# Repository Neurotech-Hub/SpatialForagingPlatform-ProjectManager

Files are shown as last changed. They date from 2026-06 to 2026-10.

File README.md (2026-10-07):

# Spatial Foraging Platform

A modular home-cage platform that converts the cage floor into a programmable
foraging environment for freely moving rodents. Distributed reward delivery and
spatial cueing within a scalable, synchronized architecture enable continuous,
ethologically grounded behavior compatible with chronic neural recordings.

**[View design (Fusion 360)](https://a360.co/4dwOh8e)** — 3D model and mounting
outline. Mounting DXF and fastener notes live in [`hardware/`](hardware/).

This repository is the **planning, documentation, and manuscript hub** for the
project. Firmware, base-station GUI, and analysis code live in
[Neurotech-Hub/SFM](https://github.com/Neurotech-Hub/SFM) and are linked from
the [Related repositories](#related-repositories) table below.

Funded by the McDonnell Center NRP (PI: Gaidica). Total budget: $40,000 over 12
months. See [`references/McDonnell-NRP_GAIDICA.pdf`](references/McDonnell-NRP_GAIDICA.pdf)
for the funded proposal.

## Current status

| Field | Value |
| --- | --- |
| Phase | Phase 3A — first ABC startup; HLAB bandit learning confirmed |
| Hardware status | Alpha (ABC 2-node in first runs; one HLAB node does not fully raise) |
| Software status | Alpha (open: GUI pellet count; dome-open raise safeguard) |
| Week | Week 17 (as of 2026-10-07; see [`PROJECT.md`](PROJECT.md)) |

## Quick links

- [`PROJECT.md`](PROJECT.md) — master roadmap: phases, milestones, exit criteria, checkbox tasks
- [Operations](#operations) — flash firmware, bring up the Pi, run a session, generate reports
- [`docs/`](docs/) — design + requirements documents (architecture, dispense cycle, sync, UI/UX, calibration, etc.)
- [`docs/dispense-cycle.md`](docs/dispense-cycle.md) — dispense cycle flowchart, sensor pinouts, CAN events, and heartbeat snapshot
- [`docs/user-api.md`](docs/user-api.md) — experiment API, session CSV schema, and behavior reports
- [`docs/function-checks.md`](docs/function-checks.md) — pre-session bring-up checklist
- [`hardware/`](hardware/) — hardware design artifacts (e.g. 3D / DXF)
- [`meetings/`](meetings/) — cross-lab meeting notes
- [`pulse/`](pulse/) — weekly progress (shipped / in progress / blocked)
- [`bom/`](bom/) — budget tracking against the $40k grant
- [`references/`](references/) — grant proposal and source planning documents
- [`manuscript/`](manuscript/) — manuscript drafting (Phase 8+)
- [`CONTRIBUTING.md`](CONTRIBUTING.md) — how to contribute

## Collaborators

| Lab | Role | Lead | GitHub |
| --- | --- | --- | --- |
| Neurotech Hub (NTH) | Engineering lead — electronics, firmware, host UI, fabrication, integration, dissemination | Matt Gaidica, PhD | TBD |
| Animal Behavior Core (ABC) | UI/UX feedback, common task structures, behavioral benchmarking, animal metrics report | Susan Maloney, PhD | TBD |
| Hengen Lab (HLAB) | Custom experiment authoring, in vivo electrophysiology validation, recording sync | Keith Hengen, PhD | TBD |

## Related repositories

The repositories below hold the actual artifacts produced by this project. This
planning repo links to them; it does not contain their source.

Firmware, GUI, and analysis all live in **[Neurotech-Hub/SFM](https://github.com/Neurotech-Hub/SFM)**
(formerly VFM).

| Domain | Repository | Owner | Status |
| --- | --- | --- | --- |
| Mechanical / CAD | TBD | NTH | TBD |
| Electronics / PCB | TBD | NTH | TBD |
| Module firmware | [SFM `firmware/`](https://github.com/Neurotech-Hub/SFM/tree/main/firmware) | NTH | Active — Arduino library `SFM` (ESP32-S3) |
| Base station / host UI  | [SFM `packages/dev_gui`](https://github.com/Neurotech-Hub/SFM/tree/main/packages/dev_gui) | NTH | Active — DearPyGui + CAN tooling |
| Experiment API | [experiment engine](https://github.com/Neurotech-Hub/SFM/tree/main/packages/dev_gui/base_station/experiment) | NTH / HLAB | Built-in templates; custom via copy-from |
| Analysis / reports | [sfm-analysis](https://github.com/Neurotech-Hub/SFM/tree/main/packages/sfm-analysis) ([PyPI](https://pypi.org/project/sfm-analysis/)) | NTH / ABC  | Active — `pip install sfm-analysis` |

When a CAD or PCB repo comes online, replace `TBD` with the URL and update the
status column.

## Operations

Operator path from a flashed node to a printable report. Long-form install and
troubleshooting live in SFM; this section is the hub.

```mermaid
flowchart LR
    flash[Flash SFM firmware]
    hat[Pi CAN HAT setup-can.sh]
    gui[python run.py]
    session[Start session in GUI]
    csv["~/sfm_logs session CSV"]
    report["sfm-report"]
    flash --> hat --> gui --> session --> csv --> report
```

All commands below assume a clone of [Neurotech-Hub/SFM](https://github.com/Neurotech-Hub/SFM).
CAN bitrate is **250 kbps**. Pre-session checks:
[`docs/function-checks.md`](docs/function-checks.md).

### Firmware

The Arduino library is `firmware/` (not the repo root). Copy or symlink it to
`Arduino/libraries/SFM`, or zip that folder and add it via *Sketch → Include
Library → Add .ZIP Library…*. Pin map:
[firmware/docs/WIRING.md](https://github.com/Neurotech-Hub/SFM/blob/main/firmware/docs/WIRING.md).
Dispense cycle:
[firmware/docs/DISPENSE_CYCLE.md](https://github.com/Neurotech-Hub/SFM/blob/main/firmware/docs/DISPENSE_CYCLE.md).

### One-time Raspberry Pi CAN HAT bring-up

Do this once per Pi before running against real hardware:

```bash
cd packages/dev_gui/deploy
sudo ./setup-can.sh            # reboots automatically if needed
sudo ./setup-can.sh --verify   # confirm can0 is healthy after reboot
```

Details: [deploy/README.md](https://github.com/Neurotech-Hub/SFM/blob/main/packages/dev_gui/deploy/README.md).
HAT pin-by-pin check (from `packages/dev_gui`): `python tests/test_hat.py`.

### Install and run the GUI

```bash
cd packages/dev_gui
pip install -r requirements.txt --break-system-packages
python run.py                  # real hardware on can0; logs default to ~/sfm_logs
```

Simulator (no hardware):

```bash
sudo modprobe vcan
sudo ip link add dev vcan0 type vcan
sudo ip link set up vcan0
# Terminal 1
python node_simulator.py --interface vcan0 --nodes 3
# Terminal 2
python run.py --interface vcan0 --nodes 3
```

GUI README: [packages/dev_gui/README.md](https://github.com/Neurotech-Hub/SFM/blob/main/packages/dev_gui/README.md).

### Run a session

In the GUI: pick a template, enter a session name, click Start. Session
activate broadcasts `SyncFlash` (every online node’s status LED solid ON for
500 ms) and fires a coincident BNC OUT pulse. Logs append to
`<log_dir>/<session_name>.csv` (default `~/sfm_logs`).

The base station stores MAC↔Node ID mappings in `~/.sfm/mac_id_registry.json`.
**Re-discover** in the GUI clears that file, broadcasts `ClearId` to node NVS,
and rediscovers from scratch.

### Behavior reports

Reports run on **any** workstation — Windows, macOS, or Linux. No Raspberry Pi
or hardware libraries. Install the SDK:

```bash
pip install sfm-analysis
```

```bash
sfm-report --demo --open                 # bundled demo; no rig or logs needed
sfm-report --list
sfm-report EXP-Test-02 --open
sfm-report "cohortA_*" --combine -o /tmp/cohortA.html
```

On the Pi, `python run_report.py` (from `packages/dev_gui`) is a thin wrapper
around the same CLI and uses the base station’s log-directory auto-detection
(external drive, else `~/sfm_logs`).

Canonical docs: [sfm-analysis README](https://github.com/Neurotech-Hub/SFM/blob/main/packages/sfm-analysis/README.md)
and [ANALYSIS_GUIDE.md](https://github.com/Neurotech-Hub/SFM/blob/main/packages/sfm-analysis/docs/ANALYSIS_GUIDE.md).
Experiment API and CSV schema: [`docs/user-api.md`](docs/user-api.md).

| Design | When it applies | Extra sections |
| --- | --- | --- |
| `default` | Any session (fallback) | Pellet accounting, latency, presence, funnel, faults |
| `free_feeding` | `free_feeding` template | Intake rate, reload delays |
| `fixed_and_random` | `fixed_and_random` template | Per-node role (off / fixed / random) |
| `probability_delivery` | `probability_delivery` template | Delivery-site distribution |
| `two_armed_bandit` | `two_armed_bandit` template | Choice, block/reversal curves, WSLS |

`--combine` builds a comparative report (cohort table, learning curve, quality
matrix). Time alignment: `relative` (default), `wall`, `trial`, or `event:<name>`.
JSON export is planned (`--json`); metrics are already computed separately from HTML.

## How to read this repo

If you are new here, read in this order:

1. This README — what we are building, where artifacts live, and how to operate.
2. [`PROJECT.md`](PROJECT.md) — current phase, what is in flight, what is next.
3. [`pulse/log.md`](pulse/log.md) — weekly shipped / in progress / blocked.
4. [`docs/architecture.md`](docs/architecture.md) — system architecture.
5. The relevant `docs/*.md` for your role (e.g. ABC: `ui-ux.md`, `maintenance.md`; HLAB: `user-api.md`, `sync-and-recording.md`).

## Abbreviations

Abbreviations used throughout this repository.

### Collaborators

| Abbreviation | Expansion |
| --- | --- |
| ABC | Animal Behavior Core |
| HLAB | Hengen Lab |
| NTH | Neurotech Hub |

### Project / process

| Abbreviation | Expansion |
| --- | --- |
| BOM | Bill of Materials |
| HW | Hardware (status field) |
| MVP | Minimum Viable Product |
| SFM | Spatial Foraging Module / [Neurotech-Hub/SFM](https://github.com/Neurotech-Hub/SFM) software repo |
| SW | Software (status field) |
| VFM | Former name of SFM (GitHub repo renamed 2026-08-27) |

### Hardware / electronics

| Abbreviation | Expansion |
| --- | --- |
| CAD | Computer-Aided Design |
| CAN | Controller Area Network (bus) |
| LED | Light-Emitting Diode |
| MCU | Microcontroller Unit |
| PCB | Printed Circuit Board |
| PCBA | Printed Circuit Board Assembly |
| TTL | Transistor-Transistor Logic (digital sync signal level) |

### Software / interfaces

| Abbreviation | Expansion |
| --- | --- |
| API | Application Programming Interface |
| CLI | Command-Line Interface |
| UI | User Interface |
| UX | User Experience |

### External references

| Abbreviation | Expansion |
| --- | --- |
| FED3 | Feeding Experimentation Device 3 (open-source rodent feeder, Kravitz lab) |

## License

Documentation, plans, and manuscript content in this repository are released
under [CC-BY-4.0](LICENSE). Code in linked sub-repositories carries its own
licensing.

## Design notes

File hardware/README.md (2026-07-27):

# Hardware

Design artifacts for the Spatial Foraging Module.

## 3D / mounting outline

| Item | Location |
| ---- | --- |
| Mounting outline (DXF) | [`3D/UserDXF.dxf`](3D/UserDXF.dxf) |
| View design (Fusion) | [a360.co/4dwOh8e](https://a360.co/4dwOh8e) |

The DXF is the outline required for mounting the Spatial Foraging Module.

- **Fasteners:** 4× M3 × 16 mm screws and 8× M3 nuts
- **Bedding height:** assumes ~10 mm

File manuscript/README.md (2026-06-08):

# Manuscript

This folder holds the methods/resource manuscript describing the Spatial
Foraging Platform: engineering, behavioral validation, electrophysiology /
sync validation, and analysis examples. Active drafting begins in
[Phase 8](../PROJECT.md#phase-8--manuscript-development).

## Source material

By the time Phase 8 starts, most of the manuscript content already exists
elsewhere in this repo:

- **Methods** — synthesized from [`../docs/`](../docs/) (architecture, sync, calibration, maintenance,
  user API).
- **Behavioral validation** — from the field test in Phase 5
  (see [`../docs/validation-plan.md`](../docs/validation-plan.md)).
- **Recording validation** — from HLAB's electrophysiology in Phases 3B and 5.
- **Resource statement** — from the [main README](../README.md) and the
  related-repository index.

## Planned contents (populated in Phase 8)

- `outline.md` — section assignments and target lengths.
- `figures/` — figure source files and exports.
- `sections/` — per-section drafts.
- `submission/` — final formatted manuscript and supplementary material.

## Publication route

To be selected at the start of Phase 8. Decision recorded as an ADR.

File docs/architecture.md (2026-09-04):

# Architecture

Captures the integrated system architecture for the platform.

## System overview

The Spatial Foraging Platform is a modular, network-connected behavioral apparatus
consisting of a Raspberry Pi 5 base station and up to N foraging modules (reference
deployment: 9 modules) connected over a CAN bus in a linear daisy-chain. Each
foraging module is an independent unit housing an ESP32S3, two stepper-motor pellet
dispensers, a sensor suite comprising a pellet presence sensor, home position sensor, and spring-loaded access port trigger, and status LEDs. The base
station orchestrates node discovery, session management, event logging, HTML
behavior reports from those logs, and synchronization with external recording
systems via BNC I/O. All modules are powered
from a single 12 V supply routed through the daisy-chain; the base station is powered
separately via USB-C.

```mermaid
flowchart LR
    subgraph bs [Base Station]
        RPi5[Raspberry Pi 5]
        CANHAT[CAN HAT]
        BNC_IN1[BNC In 1]
        BNC_IN2[BNC In 2]
        BNC_OUT[BNC Out]
        RPi5 --- CANHAT
    end

    subgraph pwr [12 V Power]
        PSU[8 A Supply]
    end

    PSU -->|12 V daisy-chain| M1
    PSU -->|12 V daisy-chain| M2
    PSU -->|12 V daisy-chain| MN

    CANHAT -->|CAN bus RJ45| M1

    subgraph M1 [Module 1]
        ESP1[ESP32S3 + CAN XCVR]
        TERM1[CAN termination OFF]
    end

    M1 -->|CAN bus RJ45| M2

    subgraph M2 [Module 2]
        ESP2[ESP32S3 + CAN XCVR]
        TERM2[CAN termination OFF]
    end

    M2 -->|CAN bus RJ45| MN

    subgraph MN ["Module N (last)"]
        ESPN[ESP32S3 + CAN XCVR]
        TERMN[CAN termination ON]
    end

    ExtSys[External System] -->|TTL/BNC| BNC_IN1
    ExtSys -->|TTL/BNC| BNC_IN2
    BNC_OUT -->|TTL/BNC| ExtSys
```

## Communication protocol

CAN bus was selected as the module network protocol for the following reasons:

- **Noise immunity** — differential signalling is robust over the cable lengths
typical in a home-cage arena.
- **Bus topology** — all nodes share a single cable run; individual node wiring is
minimised.
- **Built-in error handling** — CAN hardware provides automatic retransmission, error
frames, and bus-off detection without requiring application-layer redundancy.
- **Peer-to-peer broadcasting** — any node can broadcast events to all other nodes and
to the base station simultaneously.

Bitrate is **250 kbps** (firmware TWAI and GUI `--bitrate` default).

## CAN bus topology

### Physical topology

Linear bus topology. RJ45/Ethernet connectors carry CAN signals (CAN_H, CAN_L),
12 V power, GND, and addressing GPIOs (AEO/AEI) in a daisy-chain from the base
station through every module.

### Termination

CAN requires a 120 Ω termination resistor at each end of the bus.

| End | Termination method |
| --- | --- |
| Base station | Fixed 120 Ω resistor on the CAN HAT |
| Last node | Automatic via hardware logic |

The automatic termination on the last node works as follows: when the node's CAN-out
RJ45 port is **unplugged**, hardware logic (a physical switch or pull) asserts the
termination resistor. When the port is plugged in and continues the chain, termination
is disabled. No firmware intervention is required.

### Addressing and discovery

Each node's UUID is its ESP32S3 MAC address. The base station assigns a logical Node ID
(1-based integer) during discovery and stores the UUID↔ID mapping in its registry.
Each node stores its assigned ID in ESP32S3 NVS (non-volatile storage) so it persists
across power cycles.

Discovery uses a daisy-chain Address Enable signal. Each module has:

- **AEO** — Address Enable Out (drives the next node's AEI).
- **AEI** — Address Enable In (gates whether the node participates in the current
discovery step).

#### First boot — all nodes have empty NVS

```
Base          Node A (NVS: empty)     Node B (NVS: empty)     Node C (NVS: empty)
  │                   │                        │                        │
  │  ════════════════ FIRST BOOT (all nodes are new) ═══════════════    │
  │                   │                        │                        │
  ├──AEO HIGH────────►│ AEI=HIGH               │ AEI=LOW               │ AEI=LOW
  │                   │                        │ (blocked)              │ (blocked)
  │                   │ "I have no saved ID"   │                        │
  │                   │                        │                        │
  │◄──ANNOUNCE(UUID_A)│                        │                        │
  │                   │                        │                        │
  ├──ASSIGN(UUID_A,1)►│                        │                        │
  │                   │ save {UUID_A,1} to NVS │                        │
  │◄──ACK(1)──────────│                        │                        │
  │                   │                        │                        │
  │                   ├──AEO HIGH─────────────►│ AEI=HIGH               │ AEI=LOW
  │                   │                        │ "I have no saved ID"   │ (blocked)
  │                   │                        │                        │
  │◄──────────────────────ANNOUNCE(UUID_B)─────│                        │
  │                   │                        │                        │
  ├────────────────────────ASSIGN(UUID_B,2)───►│                        │
  │                   │                        │ save {UUID_B,2} to NVS │
  │◄──────────────────────ACK(2)───────────────│                        │
  │                   │                        │                        │
  │                   │                        ├──AEO HIGH─────────────►│ AEI=HIGH
  │                   │                        │                        │ ... same ...
  │                   │                        │                        │
  │  ... silence ... (AEO of Node C goes nowhere — CAN-out unplugged)   │
  │                                                                     │
  │  ⏱ TIMEOUT (e.g., 2 seconds of no new ANNOUNCE)                    │
  │                                                                     │
  │  "Discovery complete: 3 nodes assigned"                             │
```

#### Subsequent boot — nodes already have saved IDs

```
Base          Node A (NVS: ID=1)      Node B (NVS: ID=2)      Node C (NVS: ID=3)
  │                   │                        │                        │
  │  ════════════════ NORMAL BOOT (all nodes have saved IDs) ══════    │
  │                   │                        │                        │
  ├──AEO HIGH────────►│ AEI=HIGH               │                        │
  │                   │                        │                        │
  │                   │ "I have saved ID=1"    │                        │
  │                   │ → AEO HIGH immediately │                        │
  │                   ├──AEO HIGH─────────────►│ AEI=HIGH               │
  │                   │                        │ → AEO HIGH immediately │
  │◄──REJOIN(UUID_A,1)│                        ├──AEO HIGH─────────────►│
  │                   │                        │                        │
  │◄──────────────────────REJOIN(UUID_B,2)─────│                        │
  │                   │                        │                        │
  │◄─────────────────────────────────────REJOIN(UUID_C,3)───────────────│
  │                   │                        │                        │
  │  (base station verifies all UUIDs match registry)                   │
  │                   │                        │                        │
  │  ... silence ... (AEO of Node C goes nowhere — CAN-out unplugged)   │
  │                                                                     │
  │  ⏱ TIMEOUT (e.g., 2 seconds of no new REJOIN)                      │
  │                                                                     │
  │  "Discovery complete: 3 nodes verified"                             │
```

#### Node ID organisation

After discovery, the user maps logical Node IDs to physical positions (arena layout).
Both the base station registry and each node's NVS stay in sync; a node that loses its
NVS falls back to first-boot behaviour on the next power cycle.

### CAN identifier layout

SFM uses **11-bit standard CAN identifiers** (`0x000`–`0x7FF`, 2048 IDs) with software
filtering. The identifier carries **message class and target node** only; opcodes, event
types, and payload (dispense state, pellet counts, etc.) live in the separate 0–8 byte
data field.

Operational messages use `identifier = BASE + nodeId`. The **low 8 bits** are `nodeId`
(0–255); the **upper bits** select message class (`0x1xx` commands, `0x2xx` heartbeat,
`0x3xx` events). Node IDs are 1-based; `nodeId == 0` on commands means broadcast
(`0x100`).

| Region | Range | Role |
| --- | --- | --- |
| Discovery | `0x080`–`0x083` | Boot-time ANNOUNCE, ASSIGN, ACK, REJOIN (node identified by MAC in data) |
| Commands | `0x100`–`0x1FF` | Base → node (`0x100` = all nodes) |
| Heartbeat/status | `0x200`–`0x2FF` | Node → base periodic status |
| Events | `0x300`–`0x3FF` | Node → base immediate events |
| Reserved | everything else | Unused in v1 (~1276 IDs, including `0x400`–`0x7FF`) |

Each assigned node consumes **3 operational IDs** — command, heartbeat, and event. With
N nodes: **3×N + 4 discovery + 1 broadcast** (e.g. node 4 → `0x104`, `0x204`, `0x304`).
Maximum **255 nodes** (`nodeId` 1…255). About **772 IDs** are allocated by design; the
rest of the 11-bit space is free for future message types.

## Module hardware

| Component | Detail |
| --- | --- |
| MCU | ESP32S3-Mini-1 N8 |
| CAN interface | On-board CAN transceiver |
| Connectivity | RJ45 in + RJ45 out (daisy-chain); carries CAN_H, CAN_L, 12 V, GND, AEO, AEI |
| Termination | Automated hardware logic — resistor switches in when CAN-out is unplugged |
| Actuation | 2 × stepper motor + driver (pellet dispensing) |
| Pellet sensing | 1 × pellet presence sensor (direct verification at presentation port) |
| Access sensing | 1 × pellet catch trigger (instant catch detection) |
| Position sensing | 1 × home position sensor (actuator limit) |
| Status LED | 1 × upward-facing LED (node status visibility from above) |
| General-purpose LEDs | 2 × on-board LEDs (user configurable) |
| User GPIOs | 2 × general-purpose GPIO pins |
| Power input | 12 V from daisy-chain supply |

LED colors available: **red**, **green**, **yellow**. Specific state assignments
(boot, fault, active, reward, etc.) are defined in
`[failure-modes.md](failure-modes.md)`.

## Base station hardware

| Component | Detail |
| --- | --- |
| Compute | Raspberry Pi 5 |
| CAN interface | Custom CAN HAT |
| Power | USB-C |
| CAN output | Connects to Module 1 (first node) via RJ45 |
| Sync inputs | 2 × BNC — external system to base station  |
| Sync output | 1 × BNC — base station to external system  |
| BNC isolation | 5 V isolated rail for noise immunity |
| Status LEDs | 2 × user-configurable LEDs |
| BNC indicator LEDs | 3 × LEDs (one per BNC channel) |

## Synchronization strategy

Synchronization is owned by the base station. On session start the base broadcasts
`CanCmd::SyncFlash`: every node holds its upward-facing status LED solid ON for
**500 ms** so overhead cameras can mark the same instant. A coincident **BNC OUT**
pulse goes to recording systems.

The three BNC connectors handle TTL I/O. **BNC OUT** is in use today (session-start
pulse, optional pulse on a chosen CAN event). **BNC IN 1 / IN 2** log edges and can
drive experiment callbacks; using them to **start and stop the experiment from an
external TTL** is planned — see [`sync-and-recording.md`](sync-and-recording.md).

| Connector | Direction | Purpose |
| --- | --- | --- |
| BNC In 1  | External → Base station | External trigger or clock input  |
| BNC In 2  | External → Base station | Secondary external input |
| BNC Out | Base station → External | Platform event or trigger output |

BNC signals run on an isolated 5 V rail to minimise ground loops and noise coupling to
electrophysiology systems.

## Status indicators

### Module LEDs

Each module carries three LEDs (red, green, yellow):

| LED | Placement | Notes |
| --- | --- | --- |
| Status LED | Upward-facing | Visible from above; 500 ms solid ON at session start (camera sync) |
| General LED 1 | On-board | User configurable |
| General LED 2 | On-board | User configurable |

State assignments (boot, fault, active, reward, idle, etc.) are not yet finalised.
See `[failure-modes.md](failure-modes.md)` for fault code cross-reference.

### Base station LEDs

| LED | Count | Purpose |
| --- | ----- | --- |
| User-configurable | 2 | General status |
| BNC indicator | 3 | One per BNC channel — shows signal activity |

## Power

| Parameter | Value |
| --- | --- |
| Module supply voltage | 12 V |
| Distribution | Daisy-chained through RJ45 connectors |
| Per-module worst-case current | ~450 mA |
| 9-module total | ~4 A |
| Recommended supply rating | 8 A (supports up to ~16 modules) |
| Base station supply | USB-C (independent of module rail) |

A single 8 A 12 V supply is the minimum recommended for a full 9-module deployment.
Scaling to 16 modules remains within the same supply rating at this per-module budget.

## Logging and reports

The base station appends every CAN frame, heartbeat, BNC edge, and experiment
row to one session CSV. [`sfm-analysis`](https://github.com/Neurotech-Hub/SFM/tree/main/packages/sfm-analysis)
(`pip install sfm-analysis`, CLI `sfm-report`) renders that CSV as printable
HTML (generic metrics plus per-template designs: free feeding, fixed/random,
probability delivery, two-armed bandit). On the Pi,
[`run_report.py`](https://github.com/Neurotech-Hub/SFM/blob/main/packages/dev_gui/run_report.py)
is a thin wrapper around the same CLI. Schema and commands: [`user-api.md`](user-api.md).

## Architecture diagram

```mermaid
flowchart TD
    subgraph external ["External Recording System (optional)"]
        EXT[External System]
    end

    subgraph basestation [Base Station]
        RPi5[Raspberry Pi 5]
        CANHAT[CAN HAT]
        BNC1[BNC In 1]
        BNC2[BNC In 2]
        BNCOUT[BNC Out]
        USBC[USB-C Power]
        RPi5 --- CANHAT
        RPi5 --- BNC1
        RPi5 --- BNC2
        RPi5 --- BNCOUT
    end

    subgraph power [Power Distribution]
        PSU["12 V / 8 A Supply"]
    end

    subgraph M1 [Module 1]
        M1ESP[ESP32S3]
        M1CAN[CAN XCVR]
        M1STEP[2x Stepper]
        M1PRES[Pellet Presence Sensor]
        M1ACC[Spring Access Sensor]
        M1LED[3x LED]
    end

    subgraph M2 [Module 2]
        M2ESP[ESP32S3 ...]
    end

    subgraph MN ["Module N (last node)"]
        MNESP[ESP32S3 ...]
        MNTERM["120 ohm CAN termination"]
    end

    EXT -->|TTL| BNC1
    EXT -->|TTL| BNC2
    BNCOUT -->|TTL| EXT

    CANHAT -->|RJ45 CAN + AEO/AEI| M1
    M1 -->|RJ45 CAN + AEO/AEI| M2
    M2 -->|RJ45 CAN + AEO/AEI| MN

    PSU -->|12 V daisy-chain| M1
    PSU -->|12 V daisy-chain| M2
    PSU -->|12 V daisy-chain| MN
```

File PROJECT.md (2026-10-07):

# Spatial Foraging Platform — Project Plan

## Vision

Build, validate, document, and disseminate a modular home-cage platform for
spatially structured ethological behavior, with production-ready hardware,
release-ready software, user documentation, validation datasets, and a
methods/resource manuscript.

## Strategic goals

- Converge on a modular home-cage hardware, firmware, and synchronization
architecture suitable for chronic neural-recording experiments.
- Demonstrate a working MVP custom experiment end-to-end with sync to external
recording hardware.
- Validate the platform in an n=9 module field test and refine UI/UX,
maintenance, and analysis paths based on real use.
- Deliver production-intent PCBAs and a locked BOM that fits within the
McDonnell NRP budget.
- Hand off operation to non-engineering users (ABC and HLAB) operating from
documentation alone.
- Publish a methods/resource manuscript and release the full platform (CAD,
firmware, software, docs, examples) under an open-source license.

## Timeline anchor

**Week 0**: 2026-06-08. All week ranges below derive from this date.

**Rebaseline (2026-09-16):** Phases 3A–9 slipped. HLAB has been on a
two-module alpha setup since 2026-08-14; ABC’s matching two-node behavior
box was then due Week 15 and was set up on 2026-09-30. Production 9-node
PCBAs and joint field tests have **not** started. Week numbers for Phase 3A
onward below replace the original Aug 2026 field-test plan.

## Current status

| Field | Value |
| --- | --- |
| Phase | Phase 3A — first ABC startup; HLAB bandit learning confirmed |
| Hardware status | Alpha (ABC 2-node in first runs; one HLAB node does not fully raise) |
| Software status | Alpha (open: GUI pellet count; dome-open raise safeguard) |
| Week | Week 17 (as of 2026-10-07) |

Weekly shipped / blocked / next: [`pulse/log.md`](pulse/log.md). Cross-lab
events: [`meetings/`](meetings/).

## Phase timeline

| Phase | Lead | Weeks | Calendar | Status |
| ----- | ---- | ----- | --- | --- |
| 0 Architecture | NTH | 0–1 | Jun 8–21, 2026 | Done |
| 1A UI/UX Kickoff | ABC | 2–4 | Jun 22–Jul 12, 2026 | Done |
| 1B Experiment Kickoff | HLAB | 2–4 | Jun 22–Jul 12, 2026 | Done |
| 2 Engineering Sprint | NTH | 5–7 | Jul 13–Aug 2, 2026 | Done |
| Alpha two-module deployments | NTH | 8–14 | Aug 3–Sep 20, 2026 | Closing (HLAB live; ABC box in build) |
| 3A Feedback + maintainability | ABC + HLAB | 15–17 | Sep 21–Oct 11, 2026 | Next |
| 3B Custom experiment MVP | HLAB | 18–20 | Oct 12–Nov 1, 2026 | Planned |
| 4 9-node PCBA + enclosure | NTH + HLAB | 21–24 | Nov 2–Nov 29, 2026 | Planned (boards 3–4 weeks) |
| 5 Field tests | ABC + HLAB | 25–28 | Nov 30–Dec 27, 2026 | Planned |
| 6 UI/UX refinement | NTH | 29–32 | Dec 28, 2026–Jan 24, 2027 | Planned |
| 7 User independence | ABC + HLAB | 33–40 | Jan 25–Mar 21, 2027 | Planned |
| 8 Manuscript | NTH | 41–46 | Mar 22–May 2, 2027 | Planned |
| 9 Release | NTH + ABC + HLAB | 47+ | May 2027+ | Planned |

```mermaid
gantt
  title Spatial Foraging Platform — rebaselined timeline
  dateFormat YYYY-MM-DD
  axisFormat %b %Y

  section Done
  Phase 0 Architecture           :done, p0, 2026-06-08, 2026-06-22
  Phase 1A / 1B Kickoff          :done, p1, 2026-06-22, 2026-07-13
  Phase 2 Engineering Sprint     :done, p2, 2026-07-13, 2026-08-03

  section Alpha deployments
  HLAB 2-module delivery         :milestone, m_hlab, 2026-08-14, 1d
  ABC site tour                  :milestone, m_abc_tour, 2026-08-31, 1d
  HLAB two-armed bandit alpha    :p_hlab, 2026-08-14, 2026-09-21
  ABC 2-node box build           :p_abc_build, 2026-08-31, 2026-09-21

  section Next
  ABC 2-node delivery            :milestone, m_abc, 2026-09-21, 1d
  Phase 3A Feedback + maintainability :p3a, 2026-09-21, 2026-10-12
  Phase 3B Custom experiment MVP :p3b, 2026-10-12, 2026-11-02
  Phase 4 PCBA + enclosure       :p4, 2026-11-02, 2026-11-30
  Phase 5 ABC + HLAB field tests :p5, 2026-11-30, 2026-12-28
  Phase 6 UI/UX refinement       :p6, 2026-12-28, 2027-01-25
  Phase 7 User independence      :p7, 2027-01-25, 2027-03-22
  Phase 8 Manuscript             :p8, 2027-03-22, 2027-05-03
  Phase 9 Release                :p9, 2027-05-03, 2027-06-08
```

```mermaid
flowchart TB
  subgraph nth [NTH]
    p0["Phase 0 Architecture - Jun 2026 - done"]
    p2["Phase 2 Engineering Sprint - Jul 2026 - done"]
    p4["Phase 4 9-node PCBA + enclosure - Nov 2026"]
    p6["Phase 6 UI and UX Refinement - Jan 2027"]
    p8["Phase 8 Manuscript - Mar 2027"]
    p9["Phase 9 Release - May 2027"]
    p0 --> p2 --> p4 --> p6 --> p8 --> p9
  end

  subgraph abc [ABC]
    p1a["Phase 1A UI and UX Kickoff - Jun 2026 - done"]
    p3a["Phase 3A Feedback + maintainability - Sep 2026"]
    p1a --> p3a
  end

  subgraph hlab [HLAB]
    p1b["Phase 1B Experiment Kickoff - Jun 2026 - done"]
    p3b["Phase 3B Custom MVP - Oct 2026"]
    p1b --> p3b
  end

  subgraph joint [Joint]
    p5["Phase 5 Field Tests - Dec 2026"]
    p7["Phase 7 User Independence - Jan 2027"]
    p5 --> p7
  end

  p1a --> p2
  p1b --> p2
  p2 --> p3a
  p3a --> p3b
  p3a --> p4
  p3b --> p4
  p4 --> p5
  p5 --> p6
  p6 --> p7
  p7 --> p8
```

## Phase 0 — NTH Architectural Engineering

**Weeks 0–1.** Lead: NTH. **Done.**

Converge on the hardware, communication, synchronization, and diagnostic
architecture before user-facing design begins. Architecture decisions are
captured in `[docs/](docs/)`, an initial BOM is committed, and an alpha
prototype (n=3 modules plus a base station) is sent to fab.

## Phase 1A — ABC UI/UX Kickoff

**Weeks 2–4.** Lead: ABC. Support: NTH. Parallel with Phase 1B. **Done.**

Define how a non-engineering user configures, calibrates, runs, monitors, and
maintains the system. The phase produces enough user stories, task templates,
and UI/UX direction for NTH to begin building a mockup.

## Phase 1B — HLAB User Implementation Kickoff

**Weeks 2–4.** Lead: HLAB. Support: NTH. Parallel with Phase 1A. **Done.**

Define how specialized experiments are authored, executed, synchronized, and
analyzed. The experiment API surface, sync requirements, and at least one MVP
custom experiment are specified for NTH to scaffold against.

## Phase 2 — NTH Engineering Sprint

**Weeks 5–7.** Lead: NTH. **Done.**

Convert the ABC and HLAB kickoff requirements into a usable prototype stack:
alpha module electronics brought up, base-station communications running,
basic command/event/sync paths working, and a UI/UX mockup ready for ABC
review. The 2026-07-21 joint meeting locked pellet-presence sensing and
experiment-task support into that plan.

**Weeks 8–14 (alpha deployments, not a numbered phase).** HLAB received a
two-module two-armed-bandit setup on 2026-08-14; the analysis SDK followed
about a week later. ABC toured on 2026-08-31 and chose to replicate the
Hengen Lab behavior-box assembly. ABC’s first two-node box was set up
on 2026-09-30; Katie (ABC) was trained that day. The first ABC experiment
startup was 2026-10-05.

## Phase 3A — ABC + HLAB Feedback + Maintainability

**Weeks 15–17 (2026-09-21 to 2026-10-11).** Leads: ABC + HLAB. Support: NTH.

ABC receives its first two-node behavior box (same recipe as the HLAB pair)
and both labs start using the alpha hardware in earnest. Customize
experiments to what each lab actually runs, collect UI/UX and
maintainability feedback, and lock cleaning / service assumptions before
custom-MVP work and production electronics.

Exit: ABC two-node box in daily use; written feedback from ABC and HLAB on
experiments, maintenance, and cleaning; open issues triaged for 3B vs 4 vs 6.

## Phase 3B — HLAB Custom Experiment MVP

**Weeks 18–20 (2026-10-12 to 2026-11-01).** Lead: HLAB. Support: NTH. Follows
Phase 3A.

Demonstrate that the platform can run a real custom experiment end-to-end and
synchronize with external recording hardware. A minimal animal assay produces
analyzable output and surfaces the gaps in the API, sync, and analysis paths.

Exit: one custom experiment running on HLAB hardware with analyzable session
output; API / sync gaps listed for Phase 4 and Phase 6.

## Phase 4 — NTH 9-node PCBA + Enclosure Platform

**Weeks 21–24 (2026-11-02 to 2026-11-29).** Lead: NTH. Support: HLAB.

After the custom-experiment MVP, NTH places the **9-node module PCBA**. Board
turnaround is **3–4 weeks**. While boards are in fab, NTH prepares the
platform (firmware, base station, docs, fixtures), and **Hengen Lab + NTH
design the enclosure platform** for the 9-node array. Production-intent BOM
is locked against the McDonnell NRP budget.

Exit: 9-node PCBAs in hand (or in incoming inspection); enclosure design
ready to fabricate; BOM locked.

## Phase 5 — ABC + HLAB Field Tests

**Weeks 25–28 (2026-11-30 to 2026-12-27).** Leads: ABC + HLAB. Support: NTH.

Run an n=9 module field test once boards and the enclosure platform are
ready. Evaluate mechanical reliability, sensing reliability, output quality,
and analysis readiness. Remaining UI and API issues are catalogued, and the
simplified analysis workflow remains
`[sfm-analysis](https://github.com/Neurotech-Hub/SFM/tree/main/packages/sfm-analysis)`
(`pip install sfm-analysis`).

## Phase 6 — NTH UI/UX Refinement

**Weeks 29–32 (2026-12-28 to 2027-01-24).** Lead: NTH.

Incorporate field-test feedback into final module firmware, base-station
software, UI/UX, calibration, fault reporting, sync, and data export. User
and developer documentation reach a complete draft state.

## Phase 7 — ABC + HLAB User Independence

**Weeks 33–40 (2027-01-25 to 2027-03-21).** Leads: ABC + HLAB. Support: NTH.

Transition from NTH-driven operation to user-driven operation. Final platform
software, developer documentation, and user documentation are released; ABC
and HLAB confirm they can set up, run, calibrate, and diagnose the platform
independently, and feedback is collected for any remaining production
blockers.

## Phase 8 — Manuscript Development

**Weeks 41–46 (2027-03-22 to 2027-05-02).** Lead: NTH. Support: ABC + HLAB.

Convert the engineering decisions, behavioral validation, electrophysiology /
sync validation, and analysis examples into a methods/resource manuscript.
Sections are assigned, figures prepared, and a complete draft circulated for
review.

## Phase 9 — Final Documentation + Manuscript Submission

**Weeks 47+ (2027-05-03 onward).** Lead: NTH. Support: ABC + HLAB.

Submit the manuscript and launch the platform as an open-source, supported
NTH resource. CAD, firmware, software, BOM, assembly and calibration guides,
example configurations, and analysis examples are published, and outreach to
other labs begins.

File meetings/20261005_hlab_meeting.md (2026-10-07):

# Meeting: HLAB — two-arm learning and raise faults

- **Date:** 2026-10-05
- **Time / duration:**
- **Attendees:** Jemin (NTH), Ravi Chopra (HLAB)
- **Phase:** Phase 3A — ABC + HLAB Feedback + Maintainability

## Agenda

1. Ravi’s two-armed bandit analysis
2. `PelletLost` during raise, and a node that does not fully rise
3. Presence-calibration default

## Discussion

- Ravi shared analysis from the HLAB two-module setup. Mice learn the
  two-arm task and bias toward the rich arm. After the rich arm shifts,
  they take a few trials and learn the new rich arm.
- Two hardware issues:
  1. `PelletLost` during raise.
  2. One node does not raise all the way to the top. Cause not identified
     in the meeting.
- Ravi suggested touch factor **80** as the default for calibration.
- Follow-up after the meeting (Jemin, from the logs): `PelletLost` during
  raise is not a pellet falling off the plate. A mouse sitting at an open
  dome grabs the pellet while the plate is still rising, the pellet sensor
  goes empty, and the module reports `PelletLost`.

## Decisions

- Next firmware safeguard, not built yet: do not let a mouse take a pellet
  while the dome is open during the raise.
  - If the dome is open, keep the pellet at the loading position.
  - If the dome opens while the pellet is rising, lower the actuator
    immediately so the mouse cannot take the early pellet.

## Action items

| Owner | Action |
| ----- | --- |
| NTH | Dome-open safeguard: hold at load if the dome is already open; abort the raise and lower if the dome opens mid-travel |
| NTH | Find why one HLAB node does not reach the top |
| NTH | Consider touch factor 80 as the calibration default |

## Open questions / parking lot

- Which node fails to finish the raise, and whether that is a stall,
  a sensor, or a mechanical stop.
- Touch factor 80 is Ravi’s recommendation; it is not yet the shipped
  default.

## References

- Related ADRs:
- Related docs: [`docs/failure-modes.md`](../docs/failure-modes.md)
  (`PelletLost`), [`docs/dispense-cycle.md`](../docs/dispense-cycle.md)
- Related PROJECT.md phase / goals:
  [Phase 3A — ABC + HLAB Feedback + Maintainability](../PROJECT.md#phase-3a--abc--hlab-feedback--maintainability)
- HLAB delivery:
  [2026-08-14](20260814_meeting.md)

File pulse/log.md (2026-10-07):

# Pulse log

Newest week first. Project weeks start Monday 2026-06-08. Entries below are
reconstructed from this repo, linked SFM work, and meeting notes — fill gaps
where memory is better than the paper trail.

---

# Week 17 — 2026-10-05 to 2026-10-11

- **Phase:** Phase 3A — ABC + HLAB feedback and maintainability
- **HW / SW:** Alpha / Alpha
- **Meetings this week:**
  [2026-10-05 ABC weekly with Katie](../meetings/20261005_abc_meeting.md),
  [2026-10-05 HLAB with Ravi](../meetings/20261005_hlab_meeting.md)

## Shipped

- First ABC experiment startup with Katie (2026-10-05). Pre-run procedures
  and system operation walked through on the box.
- HLAB two-arm analysis: mice bias to the rich arm, and after a shift they
  relearn in a few trials.

## In progress

- ABC requests: overnight runs, a feeding path if a session is paused, a
  second option if mice have not found food in about 24 hours, and pellet
  counts on the GUI.
- Whether FED4 shares the ABC box with SFM is still undecided.
- HLAB: one node does not raise all the way to the top.
- Touch factor 80 is Ravi’s suggested calibration default; not adopted yet.

## Blocked / risks

- `PelletLost` during raise at HLAB is mice grabbing the pellet while the
  plate is still coming up, not a pellet falling off. No safeguard yet.

## Next week

- Firmware: if the dome is open, keep the pellet at the load position; if
  the dome opens mid-raise, lower immediately.
- GUI pellet count for ABC.
- Identify the HLAB node that does not finish the raise.

## Notes

- Phase 3A runs through 2026-10-11. Phase 3B (HLAB custom MVP) is the
  following window.

---

# Week 16 — 2026-09-28 to 2026-10-04

- **Phase:** Phase 3A — ABC + HLAB feedback and maintainability
- **HW / SW:** Alpha / Alpha
- **Meetings this week:**
  [2026-09-30 ABC monthly — box setup and Katie training](../meetings/20260930_meeting.md)

## Shipped

- ABC two-node behavior box set up on site (2026-09-30).
- Katie (ABC) trained on basic operations and system handling.
- Matt walked the monthly ABC meeting through updates since the last ABC
  meeting: sensors, logging, and the reporting tool are behaving.

## In progress

- Susan Maloney (ABC) protocol approval. Clarification question is in;
  hope is approval by Friday 2026-10-02.
- HLAB remains on the Aug 14 two-module setup.

## Blocked / risks

- ABC animal experiments cannot start until the behavior protocol is
  approved.

## Next week

- If approval lands, Katie leads the first ABC experiments (week of
  2026-10-05).
- NTH supports those first runs.

## Notes

- Phase 3A window is weeks 15–17 (through 2026-10-11).

---

# Week 15 — 2026-09-21 to 2026-09-27

- **Phase:** Phase 3A — ABC + HLAB feedback and maintainability
- **HW / SW:** Alpha / Alpha
- **Meetings this week:** none recorded

## Shipped

- No meeting recorded. ABC box was not yet installed (setup landed
  2026-09-30).

## In progress

- ABC two-node behavior box, carried from the Week 15 delivery target
  into the Week 16 install.

## Blocked / risks

-

## Next week

- Install the box at ABC and train an operator.

## Notes

- Rebaseline had targeted Week 15 for delivery. Install and training
  happened at the start of Week 16.

---

# Week 14 — 2026-09-14 to 2026-09-20

- **Phase:** Alpha deployments closing; Phase 3A starts Week 15
- **HW / SW:** Alpha / Alpha
- **Meetings this week:** none yet (three earlier events filled in:
[2026-07-21](../meetings/20260721_meeting.md),
[2026-08-14](../meetings/20260814_meeting.md),
[2026-08-31](../meetings/20260831_meeting.md))

## Shipped

- Meeting notes for the three major cross-lab events to date.
- Rebaselined `[PROJECT.md](../PROJECT.md)`: Phases 3A–9 no longer treated
as done/active. Production PCBA and n=9 field tests have not started.

## In progress

- ABC first two-node behavior box (HLAB assembly recipe), due next week.
- HLAB continues on the Aug 14 two-module two-armed-bandit setup.

## Blocked / risks

- Phase 5 field tests cannot start until 9-node PCBAs and the enclosure
platform exist (Phase 4, Nov 2026). Calling this week “Phase 5” was
the old plan, not the bench.

## Next week

- Deliver ABC two-node behavior box (Week 15).
- Start Phase 3A: customize experiments; collect ABC + HLAB feedback and
maintainability notes.

## Notes

- Timeline rebaseline 2026-09-16. Original plan had Phase 5 in weeks
12–16; actual sequence is 3A (feedback) → 3B (custom MVP) → 4 (9-node
PCBA + enclosure, 3–4 week fab) → 5 (field tests).

---

# Week 13 — 2026-09-07 to 2026-09-13

- **Phase:** Alpha deployment — ABC two-node box in build
- **HW / SW:** Alpha / Alpha
- **Meetings this week:** none recorded

## In progress

- ABC two-node behavior box (HLAB assembly recipe).
- HLAB two-module two-armed bandit still in use.

## Next week

- Finish ABC two-node box for Week 15 delivery.

## Notes

- Later rebaseline (Week 14): n=9 field tests are Phase 5 (Nov–Dec), not
this window.

---

# Week 12 — 2026-08-31 to 2026-09-06

- **Phase:** Alpha deployment — ABC install path
- **HW / SW:** Alpha / Alpha
- **Meetings this week:**
[2026-08-31 ABC site tour](../meetings/20260831_meeting.md)

## Shipped

- ABC site tour (2026-08-31): retrofit vs replicate the HLAB behavior-box
assembly; cleaning protocol; ABC first pair will follow the Hengen
recipe.
- Planning hub brought in line with Neurotech-Hub/SFM (VFM→SFM rename,
operator workflow, `sfm-analysis`).

## In progress

- ABC two-node behavior box build (not n=9 field test).
- HLAB continues on the Aug 14 two-module setup.  

## Next week

- Continue ABC two-node box; HLAB remains on delivered hardware.

## Notes

- Later rebaseline (Week 14): this tour was **not** Phase 5 start. Phase 5
is n=9 field tests after the 9-node PCBA and enclosure (weeks 25–28).

---

# Week 11 — 2026-08-24 to 2026-08-30

- **Phase:** Alpha deployment
- **HW / SW:** Alpha / Alpha
- **Meetings this week:** none recorded

## Shipped

- Software repo renamed VFM → SFM (2026-08-27) on GitHub
([Neurotech-Hub/SFM](https://github.com/Neurotech-Hub/SFM)).

## In progress

- ABC tour prep (Week 12).
- HLAB continues on the two-module setup.

## Next week

- ABC tour; decide retrofit vs replicate HLAB behavior-box assembly.

## Notes

- No commits in this planning repo this week; rename landed in SFM.
- 9-node PCBA was not placed this week (that is Phase 4, after custom MVP).

---

# Week 10 — 2026-08-17 to 2026-08-23

- **Phase:** Alpha deployment — analysis SDK
- **HW / SW:** Alpha / Alpha
- **Meetings this week:** none recorded (SDK follow-up from Aug 14)

## Shipped

- Analysis report SDK delivered (~2026-08-21), as discussed at the Aug 14
HLAB handover: `sfm-analysis` / `sfm-report`.
- Reporting and sync documentation.
- Bandit test HTML report (`docs/Bandit_test_01_report.html`).

## In progress

- HLAB two-module two-armed bandit on delivered hardware.
- ABC still without a box (tour scheduled Week 12).

## Next week

- VFM→SFM alignment; prep ABC tour.

## Notes

- Production 9-node PCBA is Phase 4 (Nov), not this week.

---

# Week 9 — 2026-08-10 to 2026-08-16

- **Phase:** Alpha deployment to HLAB
- **HW / SW:** Alpha / Alpha
- **Meetings this week:**
[2026-08-14 first SFM delivery to HLAB](../meetings/20260814_meeting.md)

## Shipped

- First SFM delivery to Hengen Lab (Ravi Chopra), 2026-08-14: two-module
setup with two-armed bandit.

## In progress

- HLAB bring-up on the two-module pair.
- Analysis report SDK discussed at handover; due about a week later.

## Next week

- Deliver `sfm-analysis` / `sfm-report` (~2026-08-21).
- Support HLAB bench use.

## Notes

- No commits in this planning repo this week. Custom-experiment MVP
(Phase 3B) is still later; this is the HLAB alpha pair.

---

# Week 8 — 2026-08-03 to 2026-08-09

- **Phase:** Alpha deployment prep
- **HW / SW:** Alpha / Alpha
- **Meetings this week:** none recorded

## Shipped

- BOM part-number correction and M2 screw updates.

## In progress

- First HLAB two-module delivery scheduled for the following week.
- Production-intent 9-node electronics still open (Phase 4, later).

## Next week

- First HLAB hardware delivery (two-module two-armed bandit).

## Notes

- 

---

# Week 7 — 2026-07-27 to 2026-08-02

- **Phase:** Phase 2 — Engineering sprint (close)
- **HW / SW:** Alpha / Alpha
- **Meetings this week:** none recorded

## Shipped

- Project status advanced to Phase 2 / Week 7; July 21 meeting captured.
- Module mounting hardware documented; Fusion design link surfaced.
- Electronics BOM committed.
- Dispense logic for pellet-presence sensing.
- Motor-screw and BOM spreadsheet updates.

## In progress

- Week 8 rollout to ABC/HLAB (from July 21 discussion).
- Bedding offset and pellet-detector priority from that meeting.

## Blocked / risks

- IACUC protocol amendment still outstanding (Matt brief).

## Next week

- HLAB two-module delivery; ABC box still later.

## Notes

- 

---

# Week 6 — 2026-07-20 to 2026-07-26

- **Phase:** Phase 2 — Engineering sprint
- **HW / SW:** Alpha in progress / Alpha software demonstrating connectivity
- **Meetings this week:**
[2026-07-21 initial ABC + HLAB discussion](../meetings/20260721_meeting.md)

## Shipped

- Cross-lab intro: implementation plan; pellet-presence sensing; experiment
tasks. Hardware (Matt) and alpha software (Jemin).

## In progress

- Beam-break sensor PCBs (expected July 28 as of the meeting).
- 3D design finalization; build week and beta distribution prep.
- Home-cage bedding offset; pellet detector brought forward.

## Blocked / risks

- IACUC amendment needed for home-cage intent.

## Next week

- Sensor PCB arrival; lock mechanical design; document mounting.

## Notes

- Decisions: prioritize pellet detector; add bedding offset; pursue IACUC
amendment.

---

# Week 5 — 2026-07-13 to 2026-07-19

- **Phase:** Phase 2 — Engineering sprint
- **HW / SW:** Alpha / Alpha
- **Meetings this week:** none recorded

## Shipped

- `docs/failure-modes.md` and `docs/function-checks.md`.

## In progress

- Engineering sprint: bring-up, communications, command/event/sync paths,  
UI mockup for ABC.

## Next week

- ABC + HLAB intro meeting.

## Notes

- 

---

# Week 4 — 2026-07-06 to 2026-07-12

- **Phase:** Phase 1A / 1B close
- **HW / SW:** Alpha / Alpha
- **Meetings this week:** none recorded

## Shipped

- No commits in this planning repo.

## In progress

- ABC UI/UX kickoff and HLAB experiment-kickoff requirements feeding Phase 2.

## Next week

- Phase 2 engineering sprint.

## Notes

- 

---

# Week 3 — 2026-06-29 to 2026-07-05

- **Phase:** Phase 1A / 1B Kickoff
- **HW / SW:** Architecture frozen; alpha in fab / not yet
- **Meetings this week:** none recorded

## Shipped

- No commits in this planning repo.

## In progress

- User stories / task templates (ABC) and experiment API / sync / MVP spec  
(HLAB).

## Next week

- Close kickoff phases; start engineering sprint.

## Notes

- 

---

# Week 2 — 2026-06-22 to 2026-06-28

- **Phase:** Phase 1A / 1B Kickoff
- **HW / SW:** Architecture documented / not yet
- **Meetings this week:** none recorded

## Shipped

- Architecture document: CAN topology, identifier layout, module hardware.

## In progress

- ABC UI/UX kickoff and HLAB implementation kickoff (parallel).

## Next week

- Continue kickoff requirements for the engineering sprint.

## Notes

- 

---

# Week 1 — 2026-06-15 to 2026-06-21

- **Phase:** Phase 0 — Architecture
- **HW / SW:** Architecture / not yet
- **Meetings this week:** none recorded

## Shipped

- No commits in this planning repo.

## In progress

- Hardware, communication, sync, and diagnostic architecture.
- Initial BOM and alpha prototype (n=3 + base station) to fab.

## Next week

- Publish architecture doc; start ABC/HLAB kickoffs.

## Notes

- 

---

# Week 0 — 2026-06-08 to 2026-06-14

- **Phase:** Phase 0 — Architecture
- **HW / SW:** Planning / planning
- **Meetings this week:** none recorded

## Shipped

- Project manager repo initialized.
- `PROJECT.md` timeline anchored: Week 0 = 2026-06-08.
- Collaborator abbreviations and phase structure.

## In progress

- Architectural engineering before user-facing design.

## Next week

- Close architecture decisions into `docs/`.

## Notes

-

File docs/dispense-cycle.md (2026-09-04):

# Dispense cycle

How an SFM node delivers a pellet, how it knows the pellet was taken, and what it reports along the way.

## Sensors

Each node has three optical sensors, named for the job they do.

| Sensor | Pin | Asserted when | Job |
| --- | --- | --- | --- |
| **Pellet sensor** | GPIO46 | beam broken (pin LOW) | A pellet is sitting on the plate. Latching: it stays asserted from the moment the pellet lands until the pellet leaves |
| **Load position sensor** | GPIO45 | beam broken (pin LOW) | The actuator is at the load position (fully down) |
| **Dome sensor** | GPIO44 | pin HIGH (idle LOW) | The dome is lifted. The dome is spring-returned, so every access is a clean lift-and-release bout |

All three are debounced in firmware by `kSensorDebounceMs` before any logic or reporting acts on them.

A fourth input, **animal presence**, is the capacitive touch pad. It is independent of the dispense cycle and
is reported for behavioral context only.

The pellet sensor sits on the plate and reports occupancy in every state. Because it holds its state, the node
always knows whether the plate is occupied — before a dispense, during travel, and after an access.

## The cycle

```
 Dispense
    │
    ▼
 Occupancy check (pellet sensor)
    │
    ├─ plate occupied ─► FeedSkipped ──────────────────────┐
    │                                                      │
    └─ plate empty ─► Lowering ─► Feeding                  │
                              │                            │
                         presence asserts                  │
                              │                            │
                         PelletLoaded ─────────────────────┤
                                                           ▼
                                                        Raising
                                                           │
                               pellet sensor clears ─► Fault (PelletLost)
                                                           │
                                                     PelletPresented
                                                           │
                       ┌─ dome lifts ──────► DomeOpened ───┤
                       │                                   │
                       └─ dome held open ──► DomeOpenWarning
                                                           │
                               pellet sensor clears ─► PelletTaken ─► Idle
```

**Occupancy check.** On `Dispense` the node reads the pellet sensor first. If a pellet is already on the
plate it does not lower and does not run the feed wheel: it reports `FeedSkipped` and raises what is there
(or stays presented if the plate is already elevated). A node never stacks a second pellet on an occupied plate.

**Lowering.** Only when the plate is empty. The actuator seeks the load position: if it is already there it
first moves clear, then approaches until the load position sensor asserts. Both directions are budgeted by
`kDefaultLowerSteps` and `kDefaultLowerTimeoutMs`.

**Feeding.** M1 turns the pellet wheel until the pellet sensor asserts, which confirms a pellet has arrived on
the plate. The node halts M1, reports `PelletLoaded`, and begins the raise in the same tick. If no pellet
arrives within `kDefaultFeedTimeoutMs` — an empty hopper or a wheel jam — the node faults with `Timeout`.

**Raising.** M2 lifts the plate by `kDefaultRaiseSteps` from the load position. Two checks run during travel:
the load position sensor must clear within `kLoadClearOnRaiseMs` (otherwise `Jam`), and the pellet sensor must
stay asserted. A pellet that falls off in transit clears the sensor for `kPelletLostMs` and faults with
`PelletLost`, so an empty plate is never presented as if it held a pellet.

**Presented.** The pellet is available to the animal. The node stays here, watching two things:

- Every dome lift reports `DomeOpened`. There is no suppression window — one event per bout, and the
  spring return guarantees each bout is a distinct edge.
- A dome left open for `kDomeOpenWarnMs` reports `DomeOpenWarning` once per bout. This is a warning, not a
  fault: the node keeps operating.

**Taken.** When the pellet sensor clears for `kPelletTakenConfirmMs`, the pellet is gone. The node reports
`PelletTaken` and returns to `Idle` — the cycle is complete. The confirm window rejects momentary sensor
flicker as the animal reaches past the beam.

A node never reloads on its own. Deciding when the next `Dispense` goes out belongs to the base station or the
running experiment.

## Events

Node → base on CAN ID `0x300 + nodeId`. Byte 0 is the event code.

| Code | Event | Extra payload | Meaning |
| ---- | ----- | --- | --- |
| `0x01` | `PelletLoaded` | count LE16 | A pellet is confirmed on the plate; the raise is starting |
| `0x02` | `PelletPresented` | count LE16 | The plate reached the top; the pellet is available |
| `0x03` | `DomeOpened` | count LE16, pellet present | The dome was lifted while a pellet was presented |
| `0x04` | `Fault` | `ServiceStatus` | Motion or delivery failure; sticky until `Abort` |
| `0x05` | `Pong` | — | Reply to `Ping` |
| `0x06` | `InputChanged` | input id, active | A sensor changed state |
| `0x07` | `Lowering` | count LE16 | Phase entered: seeking the load position |
| `0x08` | `Loading` | count LE16 | Phase entered: pellet wheel turning |
| `0x09` | `Raising` | count LE16 | Phase entered: lifting the plate |
| `0x0A` | `DomeOpenWarning` | count LE16 | The dome has been open for `kDomeOpenWarnMs` |
| `0x0B` | `PelletTaken` | count LE16, dome open | The pellet left the plate; retrieval confirmed |
| `0x0C` | `FeedSkipped` | count LE16 | A dispense arrived with the plate occupied; feed and lower were skipped |

`count` is the running total of pellets presented by that node.

The context byte on dome and take events separates intent from accident. `DomeOpened` carries whether a
pellet was on the plate at the moment of the lift, so an opening with an empty plate is recognizable as
exploration rather than retrieval. `PelletTaken` carries whether the dome was open when the plate emptied: open
means a normal retrieval, closed means the pellet left without an access and the mechanism deserves a look.

`InputChanged` payloads are `[0x06, inputId, active]` with input IDs pellet sensor = `1`, load position = `2`,
dome = `3`, animal presence = `4`. These fire on every debounced edge so the base station sees sensor activity
immediately; heartbeats are the periodic recovery snapshot.

## Faults

A fault halts both motors, latches a status code, lights the status LED solid, and holds the node in `Fault`
until it receives `Abort`.

| Code | Cause |
| ---- | ----- |
| `Timeout` | A motion phase exceeded its budget — no pellet loaded, or the actuator never reached its target |
| `Jam` | The load position sensor did not clear after the raise started; the plate is obstructed |
| `PelletLost` | The pellet left the plate during the raise |

## Heartbeat snapshot

Node → base on CAN ID `0x200 + nodeId`, sent every `kDefaultHeartbeatIntervalMs` (runtime-configurable via
`SetConfig`).

| Byte | Content |
| ---- | --- |
| 0 | Dispense state |
| 1–2 | Pellets presented (LE16) |
| 3 | Animal presence (touch) |
| 4 | Sensor bits: `bit0` pellet present, `bit1` at load position, `bit2` dome open |
| 5 | Fault code |
| 6–7 | Pellets taken (LE16) |

Carrying both counts means a node that reconnects mid-session reports delivery and consumption together, with
no need to replay the event log.

## What the base station can conclude

The pellet sensor turns several inferences into measurements:

- **Consumption, not delivery.** `PelletPresented` counts what the hardware offered; `PelletTaken` counts what
  the animal actually took. The gap between the two counts is the untouched pellets.
- **Unrewarded openings.** A dome bout that closes with the pellet sensor still asserted is an access that did
  not end in retrieval — a distinct behavioral event from a successful one.
- **Retrieval latency.** The interval from `PelletPresented` to `PelletTaken` is a per-pellet measure of how
  quickly the animal engaged.
- **Consumption-paced reloading.** An experiment can wait for `PelletTaken` before dispensing again, so the
  session follows the animal rather than a fixed schedule. The built-in free-feeding template works this way.
- **Abandonment.** A pellet presented and never taken is visible directly, which lets a task stop reloading
  in front of a disengaged animal instead of accumulating stale pellets.

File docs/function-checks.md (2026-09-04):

# Function Checks

System-level bring-up and verification procedures to confirm the platform is healthy before an experiment.

> [!NOTE]
> This procedure evaluates the platform from a **whole-system perspective** (Base Station + connected SFM node array). It assumes that the `SFM` Arduino library is already flashed to all nodes.

---

## 1. System power-on & LED status check

Power on the 12 V power supply (daisy-chained to all modules) and boot the Raspberry Pi base station. Observe the **Status LED** on each connected module across the arena:

| Phase | Status LED | Meaning |
| :---- | :--- | :--- |
| **Booting** | Slow blink (1 s) | `begin()` executing; hardware initializing |
| **Waiting for discovery** | Slow blink (1 s) | CAN controller active, awaiting AEI signal from base station |
| **Unassigned (no ID)** | **Continuous slow blink** | Node has no saved NVS ID; awaiting base station AEI HIGH pulse |
| **ID assigned & online** | **Off** | Node assigned valid CAN Node ID, heartbeat active, operational |
| **Fault** | Red blink pattern | Active sticky fault (Jam, Timeout); see [`failure-modes.md`](failure-modes.md) |
| **Warning** | Yellow blink pattern | Non-sticky warning (e.g. dome held open > 30 s) |

> [!IMPORTANT]
> If a module's status LED blinks continuously after power-on, it is waiting for ID assignment. This is normal behavior prior to the base station initiating the discovery FSM and driving the AEI line HIGH.

---

## 2. Automated node discovery & daisy-chain assignment

Connect all modules to the base station in a linear daisy-chain via RJ45 cables. When the base station software initializes:

1. Base station asserts **AEI HIGH** on Module 1.
2. Module 1 FSM transitions: `WaitAEI → CheckNVS`.
   - **First boot (NVS empty)**: Transitions to `Announce`, broadcasts MAC address over CAN, waits for `AssignId` command.
   - **Rejoin boot (NVS has saved ID)**: Transitions to `Rejoin` and immediately asserts AEO HIGH to downstream module.
3. Upon receiving `ASSIGN(MAC, nodeId)`, the module saves its Node ID to NVS, turns **off** its status LED, and propagates AEO HIGH to Module 2.
4. The process repeats sequentially down the chain until all $N$ modules are assigned IDs and emitting CAN heartbeats (`0x200 + nodeId`) every ~5 s.

**Expected result**: All module status LEDs turn off; all connected nodes appear online in the base station GUI grid.

---

## 3. GUI node status monitoring

The base station GUI (`packages/dev_gui`) receives live telemetry and heartbeats from all nodes on the bus. Each node's card displays its real-time SFM state machine status:

| GUI Node State | Description |
| :--- | :--- |
| **Idle** | Node online, in standby position; ready for dispense commands |
| **Lowering** | Actuator (M2) lowering to home position until home position sensor (PG2) triggers |
| **Feeding** | Feed motor (M1) rotating until pellet presence sensor confirms pellet at presentation stage |
| **Raising** | Actuator (M2) raising pellet by target steps (`raiseSteps`, ~700 steps) to presentation port |
| **Presented** | Pellet presented at port; spring access sensor detects catch attempts and pellet presence sensor confirms retrieval |
| **SeekingAway** | Actuator (M2) moving up away from home until PG2 clears (recovery/clear motion) |
| **Fault** | Sticky error state (Jam, Timeout); requires an `Abort` command from GUI to reset |
| **Offline** | Watchdog state: base station received no heartbeat for > 15 s (card highlighted red) |

---

## 4. System-wide bus ping & spatial location check

From the base station GUI, issue a **Ping All** command (`CanCmd::Ping` broadcast) or target individual Node IDs:

1. Every active node responds with a `Pong` event (`CanEvent::Pong`) containing its **MAC address** and **Node ID**, which populates the GUI event log.
2. The target node executes a **fast LED blink** pattern on its status LED, allowing visual verification of physical node locations within the arena.

> [!TIP]
> Use Ping All prior to an experiment to verify full CAN bus reachability across all nodes simultaneously and confirm that Node IDs match physical cage positions.

---

## 5. System dispense sequence & sensor verification

Trigger a dispense cycle from the base station GUI (individual module test or sequence across the array). Verify that the system executes the full SFM dispense sequence and sensor transitions:

```mermaid
stateDiagram-v2
    [*] --> Idle
    Idle --> Lowering : Dispense command
    Lowering --> Feeding : PG2 triggered (Home LOW)
    Feeding --> Raising : Pellet presence detected
    Raising --> Presented : M2 target steps reached
    Presented --> Lowering : New Dispense command / Pellet retrieved
    Presented --> Idle : Abort command
    Lowering --> Fault : Lowering Timeout / Jam
    Feeding --> Fault : Feed Timeout / Presence Sensor Fault
    Raising --> Fault : Raising Timeout / PG2 Jam
    Fault --> Idle : Abort command
```

### Dispense sequence phases

1. **Lowering**: Base station sends `Dispense`. Actuator motor (M2) runs DOWN until **PG2 (home position sensor)** is tripped (LOW).
2. **Feeding**: Feed motor (M1) rotates to advance a pellet. The **pellet presence sensor** detects and verifies pellet presence at the presentation stage.
3. **Raising**: Actuator motor (M2) runs UP for `raiseSteps` (bench default: 700 steps) to elevate the pellet to the presentation port.
4. **Presented**: Pellet is held at the presentation port. The node latches a `PelletPresented` CAN event (`0x300 + nodeId`) and increments its internal pellet count. The **spring-loaded access port mechanism** detects animal access and catch attempts. Upon an access attempt (spring trigger), the **pellet presence sensor** instantly evaluates pellet presence with confidence, determining whether the pellet was successfully retrieved or missed.
5. **Cycle completion / Next trial**: A subsequent `Dispense` command or confirmed pellet retrieval transitions the node directly from `Presented` into `Lowering` for the next pellet, while an `Abort` command returns the node to `Idle`.

---

## 6. Base station hardware & driver validation

Verify the base station hardware (Raspberry Pi 5 + CAN HAT) and host software stack:

### Interactive HAT validation (`test_hat.py`)

Run the automated interactive bring-up tool on the Raspberry Pi:

```bash
cd packages/dev_gui
python tests/test_hat.py
```

The checklist validates all base-station hardware interfaces:

| Section Flag | Hardware / Interface Validated |
| :--- | :--- |
| `can` | SPI/MCP2515 interface, CAN loopback self-test, live node discovery |
| `aeo` | AEO (GPIO27) daisy-chain enable output drive |
| `bnc_out` | BNC OUT (GPIO6) pulse timing and idle state |
| `bnc_in` | BNC IN 1 / BNC IN 2 (GPIO12/13) edge detection & level sensing |
| `button` | User button (GPIO3) input |
| `full_loop` | End-to-end loopback: BNC IN 1 → CAN broadcast dispense → BNC OUT pulse |

### Host software pytest suite

Base-station tests (GUI, CAN, experiments, discovery, node registry) and
report/analysis tests are two separate suites now that reporting lives in
`sfm-analysis`:

```bash
# Base station (from the SFM repo)
cd packages/dev_gui
pip install -r requirements.txt   # includes -e ../sfm-analysis
python -m pytest tests/ -v

# Report / analysis SDK
cd packages/sfm-analysis
pip install -e ".[dev]"
pytest
```

| Test File | Scope |
| :--- | :---- |
| `test_app.py` | GUI application lifecycle |
| `test_discovery_manager.py` | Node discovery state machine logic |
| `test_hat.py` | Interactive HAT hardware validation (not pytest) |
| `test_log_manager.py` | CSV event logging and timestamping |
| `test_mac_id_registry.py` | Persistent MAC-to-Node ID mapping |
| `test_node_registry.py` | Node FSM registry and heartbeat watchdog |
| `test_protocol.py` | CAN frame encoding/decoding |
| `test_run_report_shim.py` | `run_report.py` wrapper around `sfm-report` |
| `test_schedule.py` | Session scheduling and task execution |
| `packages/sfm-analysis` pytest | HTML behavior reports (loader, metrics, designs, render) |

---

## 7. End-to-end system bring-up checklist

Perform this full system check before initiating an experimental session:

1. **Power & Bus**: Turn on 12 V power supply and boot Raspberry Pi base station.
2. **Launch GUI**: From `packages/dev_gui`, start the base station software (`python run.py`).
3. **Verify Discovery**: Confirm all connected nodes complete daisy-chain assignment, appear in the GUI grid with correct Node IDs, and status LEDs turn OFF.
4. **Bus Reachability (`Ping All`)**: Trigger `ping_all` from GUI; verify all nodes fast-blink status LEDs and emit `Pong` events.
5. **Dispense Cycle Verification**: Trigger a dispense on each module; verify state machine sequence: `Idle → Lowering → Feeding → Raising → Presented`.
6. **BNC Synchronization**: Send a test pulse to BNC IN 1; confirm edge is recorded in the GUI log and BNC OUT pulse is generated.
7. **Camera sync flash**: Start a session; every online node’s upward-facing status LED stays solid ON for ~500 ms and BNC OUT pulses at the same moment (see [`sync-and-recording.md`](sync-and-recording.md)). Faulted nodes skip the flash.
8. **Offline Watchdog Test**: Disconnect an RJ45 cable from one module; confirm GUI updates node state to **Offline** within ~15 s.
9. **Rejoin Verification**: Reconnect the RJ45 cable; confirm node auto-rejoins and returns to **Idle**.

### Simulated system test (software-only mode)

To verify host software functionality without physical hardware attached:

```bash
cd packages/dev_gui

# Setup virtual CAN interface
sudo modprobe vcan
sudo ip link add dev vcan0 type vcan
sudo ip link set up vcan0

# Terminal 1 — launch node simulator (e.g. 9 nodes)
python node_simulator.py --interface vcan0 --nodes 9

# Terminal 2 — launch GUI connected to vcan0
python run.py --interface vcan0 --nodes 9
```

---

## 8. Standalone bench troubleshooting reference

If a specific module fails system checks, detach the module for bench testing using standalone sketches in `firmware/examples/`:

| Sketch | Target Subsystem Check |
| :----- | :--- |
| `CanBusTest.ino` | TWAI/CAN transceiver hardware, frame TX/RX, bus termination |
| `LEDTest.ino` | Status LED, green/yellow/red LED drive patterns |
| `SensorTest.ino` | Pellet presence sensor, home position sensor (PG2), and spring access trigger outputs |
| `StepperMotorTest.ino` | M1 (feed) and M2 (actuator) stepper motor drivers and step counts |

---

## 9. Pass / fail criteria

| Verification Step | Pass Criteria | Fail Criteria |
| :--- | :--- | :--- |
| **Node Discovery** | All status LEDs turn **OFF** after ID assignment | LED continues blinking indefinitely |
| **GUI Node State** | Live state reflects exact node FSM (`Idle`, `Lowering`, `Feeding`, `Raising`, `Presented`) | Card stuck on `Offline`, `Fault`, or state mismatch |
| **Ping Response** | Target node fast-blinks LED; `Pong` frame logged within 2 s | No response; MAC missing in log |
| **Dispense Sequence** | Smooth transition `Idle → Lowering → Feeding → Raising → Presented`; pellet detected by pellet presence sensor; confident retrieval verification via spring access trigger | Motor stall, pellet presence sensor timeout, or sticky `Fault` state |
| **CAN Loopback (`test_hat.py`)** | `[PASS] Loopback TX/RX matches` | Mismatched frame data or CAN interface down |
| **BNC Sync Pulse** | BNC OUT pulse width within ±10% of configured width | Missing pulse or incorrect pulse width |
| **Camera sync flash** | All online nodes hold status LED solid ~500 ms at session start; BNC OUT pulses; `SYNC` row in log | No flash, missing BNC OUT, or faulted nodes flashing |
| **Offline Detection** | Disconnected node transitions to **Offline** in ~15 s | Node state remains `Idle` after cable disconnect |

---

## Cross-references

- [`dispense-cycle.md`](dispense-cycle.md) — dispense cycle flowchart, CAN event codes, sensor pinouts, and FSM logic.
- [`failure-modes.md`](failure-modes.md) — fault catalog, sticky error codes, and LED patterns.
- [`maintenance.md`](maintenance.md) — preventive maintenance and calibration schedules.
- [`architecture.md`](architecture.md) — CAN ID layout, discovery protocol, and system topology.
- [`sync-and-recording.md`](sync-and-recording.md) — session-start LED flash, BNC I/O, planned TTL start/stop.
- [`user-api.md`](user-api.md) — experiment API, session CSV schema, and HTML behavior reports.

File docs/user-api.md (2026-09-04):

# User API

Defines how specialized experiments are authored, executed, synchronized,
and analyzed.

Canonical authoring guide:
[packages/dev_gui/base_station/experiment/README.md](https://github.com/Neurotech-Hub/SFM/blob/main/packages/dev_gui/base_station/experiment/README.md).
Copy-from starters:
[packages/dev_gui/examples/templates/](https://github.com/Neurotech-Hub/SFM/tree/main/packages/dev_gui/examples/templates).
Analysis SDK:
[packages/sfm-analysis](https://github.com/Neurotech-Hub/SFM/tree/main/packages/sfm-analysis).

## Experiment language / API

Hybrid: a Python `build()` factory plus a JSON parameter schema. There is no
base class to inherit. Sessions **always start from the GUI** — pick a template,
fill the form, enter a session name, click Start. Nodes stay dumb (commands in,
events out); the template decides what to do next.

A GUI-hosted template is two files with the same name:

- `packages/dev_gui/experiments/<name>.json` — GUI form (parameters, types, defaults)
- `packages/dev_gui/base_station/experiment/templates/<name>.py` — `def build(...) -> Experiment`

Dropping both files is enough; there is no central registry. Optional matching
report design lives under `packages/sfm-analysis` (see Output format below).

## Python scripting

Allowed and required for custom tasks. `build()` returns a configured
`Experiment`. Register behavior with `@exp.on_*` decorators, write a sequential
generator with `@exp.script`, or mix both. Iterate `control.nodes` — never a
hard-coded node list — so the GUI node multi-select works.

```python
from ..runner import Experiment

def build(nodes=None, *, name="my_task", delay_s=2.0, **_):
    exp = Experiment(nodes=list(nodes or [1, 2, 3]), name=name)

    @exp.on_start
    def start(control):
        for n in control.nodes:
            control.dispense(n)

    @exp.on_pellet_taken
    def reload(control, event):
        control.after(delay_s, lambda: control.dispense(event.node_id),
                      node=event.node_id)

    return exp
```

## Device functions exposed to users

All actions go through `ExperimentControl` (`control`). Dispense is a single
choke point with three automatic vetoes (halted node, cycle already in flight,
pellet already on the plate) before anything is sent on CAN.

| Call | Effect |
| ---- | --- |
| `control.dispense(node)` | Dispense on one node |
| `control.dispense(node, feed=False)` | Same motion, empty plate (bandit mimic) |
| `control.recover(node)` | Stop motion and clear a firmware fault |
| `control.broadcast_dispense()` / `broadcast_recover()` | Same, all session nodes |
| `control.bnc_pulse(duration_us=100)` | Pulse BNC OUT |
| `control.set_heartbeat_interval(node, ms)` | Reconfigure heartbeat rate |
| `control.after(seconds, cb, node=0)` / `every(...)` | Runner-clock timers |
| `control.counter` / `incr` / `set_counter` | Named integer counters |
| `control.next_trial()` | Advance trial counter (one delivery decision) |
| `control.log(name, node=0, **fields)` | Experiment row in GUI log + CSV |
| `control.stop(reason=...)` | End the session |

**Events** (`EventKind`): `ON_PLATE`, `LOADED`, `PELLET_TAKEN`,
`NO_FEED_PRESENTED`, `FEED_SKIPPED`, `FAULT`, phase events,
`PRESENCE_CHANGED`, `PG_CHANGED`, derived `DOME_OPENED` / `DOME_CLOSED`,
`NODE_ONLINE` / `NODE_OFFLINE`, and base-station `BNC_IN`, `SESSION_START`,
`SESSION_END`.

**Lifecycle**: `start_when(condition)`, `end_after(hours=…, pellets=…)`,
`end_when(condition)`. Shared helpers in `kit.py` (`session`, `wire_advance`,
`next_trial_wait`, `log_faults`).

At session activate the GUI broadcasts `CanCmd.SyncFlash` (status LED solid
~500 ms) and fires a coincident BNC OUT pulse. See
[`sync-and-recording.md`](sync-and-recording.md).

## Built-in templates

| Name | Behavior |
| ---- | --- |
| `free_feeding` | Dispense all nodes at start; after each pellet taken, wait (`fixed_delay` or `presence_clear`) and re-dispense; end on duration and/or pellet cap |
| `fixed_and_random` | Per-node role (off / fixed / random); advance by fixed delay, presence-clear, or BNC |
| `probability_delivery` | Each cycle delivers on one node, chosen by weighted random draw |
| `two_armed_bandit` | Both arms move each trial, only one delivers; reward probability flips every `block_size` trials |

## Boundary: what users can do vs what NTH must support

| Capability | User-implementable | Requires NTH support |
| --- | --- | --- |
| New experiment template (`.py` + `.json`) | Yes — drop in `templates/` + `experiments/`, relaunch GUI | No |
| Custom report design / metrics | Yes — optional files under `packages/sfm-analysis` | No (falls back to `default.json`) |
| Session start / stop, node select, logging | GUI-hosted | NTH owns the GUI host |
| CAN protocol, discovery, MAC↔ID registry | No | Firmware + `discovery_manager` / `~/.sfm/mac_id_registry.json` |
| HAT GPIO (BNC, AEO, button) | Configure labels/actions in GUI | NTH owns `io_manager` and HAT |
| Session CSV column schema | No | `sfm-analysis` log schema; NTH if columns change |
| Firmware pinout / dispense FSM | No | Node library `SFM` |

## External hardware requirements

| Item | Role |
| ---- | ---- |
| Raspberry Pi 5 + custom CAN HAT | Base station; SocketCAN `can0` at 250 kbps |
| 12 V supply (8 A recommended) | Daisy-chained module power |
| RJ45 patch cables | CAN + addressing GPIOs between nodes |
| BNC cables | Sync I/O to cameras / ephys DAQs |
| Overhead camera | Align footage to the 500 ms status-LED flash |
| 120 Ω termination | Fixed on HAT; auto on last node when CAN-out is unplugged |

Support-tool BOM items should match this list when the production BOM is locked.

## Minimum viable custom experiment

Shipped tasks are the four built-in templates above. HLAB custom work: copy a
starter from `packages/dev_gui/examples/templates/` into `templates/` +
`experiments/`, relaunch the GUI. Optional matching report design:
`packages/sfm-analysis/examples/report_design/`. Tests can use
`exp.make_runner(); runner.inject(...); runner.step(now)` with no CAN.

## Output format

The base station writes one **unified 15-column session CSV**
(`<log_dir>/<session_name>.csv`) for every CAN frame, heartbeat, BNC edge, and
experiment row. Host timestamps, `run_id`, `trial`, `source`, and `fields_json`
are on every row. Restarting under the same session name **appends** and
increments `run_id`. Clock source is the base-station host clock (see
[`sync-and-recording.md`](sync-and-recording.md)). Default log dir: `~/sfm_logs`
(or an auto-detected external drive).

Reports are generated by **[sfm-analysis](https://pypi.org/project/sfm-analysis/)**
(`pip install sfm-analysis`, CLI `sfm-report`). On the Pi,
[`run_report.py`](https://github.com/Neurotech-Hub/SFM/blob/main/packages/dev_gui/run_report.py)
is a thin wrapper around that CLI. No pandas/matplotlib; charts are inline SVG.
Combined reports (`--combine`) overlay several sessions. Demo with no rig:
`sfm-report --demo --open`.

A report **design**
(`packages/sfm-analysis/src/sfm_analysis/report/designs/<name>.json`) lists
**sections** (Python functions under `report/sections/`). The design is chosen
from the session’s `experiment` field; anything unmatched uses `default.json`.
Per-experiment metrics live in `report/analyses/` so they can be tested without
parsing HTML. A `--json` export of those metrics is planned.

Session names are parsed into subject / cohort / day via regex patterns in
`~/.sfm/report_settings.json` (defaults cover `cohortA_M014_d3`-style names).
Unmatched names still report; identity fields stay empty.

## Cross-references

- Operator install / run: [README — Operations](../README.md#operations).
- Sync wiring and timing: [`sync-and-recording.md`](sync-and-recording.md).
- Function checks before running: [`function-checks.md`](function-checks.md).
- Analysis vocabulary and log columns:
  [ANALYSIS_GUIDE.md](https://github.com/Neurotech-Hub/SFM/blob/main/packages/sfm-analysis/docs/ANALYSIS_GUIDE.md).

## Open questions

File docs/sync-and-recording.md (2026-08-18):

# Synchronization and Recording

How the platform marks experiment start for cameras and recording systems, and
how BNC I/O will later start and stop a session from an external TTL.

## Sync ownership

The **base station** is the time master. Nodes do not generate TTL; they only
flash their upward-facing status LED when the base station broadcasts
`CanCmd::SyncFlash`. All BNC I/O lives on the Raspberry Pi CAN HAT.

## Camera sync (current)

When a session **activates** (GUI Start, or later if the template has a deferred
`start_when`), the base station:

1. Broadcasts `CanCmd::SyncFlash` (`0x0A`) to all nodes.
2. Each node holds its **upward-facing status LED solid ON for 500 ms** (payload
  can override duration; firmware clamps 50–5000 ms).
3. Fires a coincident **BNC OUT** pulse so ephys/video DAQs can latch the same
  instant.

Purpose: a visible flash in overhead camera footage, aligned to the same moment
as the BNC pulse and the session-start log row — no manual clapperboard.

A node already in **Fault** ignores the flash (its status LED is already solid
for the fault). Those node IDs are listed in the logged `SYNC` row.

## BNC I/O

| Connector | Direction | Role today | Planned |
| --- | --- | --- | --- |
| BNC Out | Base → external | Pulse at session start (with the LED flash); can also pulse on a chosen CAN event (e.g. `Loaded`) | Same |
| BNC In 1  | External → base | Logged edges; templates can react (`@exp.on_bnc_in`) | **TTL start / end experiment** |
| BNC In 2  | External → base | Secondary input (same as In 1) | Spare or second trigger |

Signals run on an isolated **5 V** rail. HAT Schmitt inverters invert the BNC
inputs in hardware; host software undoes that so HIGH means TTL present.
Default BNC OUT pulse width is **10 ms** (configurable). Channels are 0-based:
`0` = IN1, `1` = IN2.

## Planned: TTL start / stop

At some point an external system (camera controller, Open Ephys, SpikeGLX, etc.)
should **start and end the experiment** over BNC rather than the GUI button.

Intended mapping (not locked):

- Rising edge on a BNC input → **start** experiment (same session-activate path
as GUI Start, including the 500 ms LED flash + BNC OUT).
- Falling edge, or a pulse on the other input → **stop** experiment.

The HAT and GUI already have per-edge action placeholders (`start_experiment` /
`stop_experiment`). This is **not** yet the operator workflow — polarity, which
input, pulse vs level, and whether a start TTL is required before GUI Start all
still need a decision.

## Timestamp schema

Every CAN frame, heartbeat, BNC edge, and experiment row lands in one session
CSV (`<log_dir>/<session_name>.csv`) with host timestamps, `run_id`, `trial`,
`source`, and `fields_json`. Restarting under the same session name **appends**
and increments `run_id`. Clock source is the base-station host clock; nodes do
not carry a shared experiment clock in the 11-bit CAN ID.

## Compatibility targets

- Overhead video — align frames to the 500 ms status-LED flash.
- Electrophysiology DAQs that accept 5 V TTL on BNC (Open Ephys, SpikeGLX, and
HLAB rigs). Exact pulse width, polarity, and jitter budget are still open.

## Verification

1. Start a session from the GUI; all online nodes flash the top LED ~500 ms;
  BNC OUT pulses; a `SYNC` row appears in the log.
2. Faulted nodes do not flash; they appear in that `SYNC` row.
3. (Once TTL start/stop is enabled) pulse BNC IN and confirm session start/stop
  plus the same LED/BNC OUT mark.

See `[function-checks.md](function-checks.md)` for HAT BNC bring-up (`test_hat.py`).

## Open questions

- BNC IN polarity and which connector starts vs stops.
- Required vs optional TTL start (GUI-only still allowed?).
- BNC OUT pulse width / polarity lock for HLAB DAQs.
- Whether session **end** also flashes LEDs, or only start.

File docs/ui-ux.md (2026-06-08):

# UI / UX

Captures how non-engineering users configure, calibrate, run, monitor, and
maintain the system.

## Primary interface

_Web app, desktop app, CLI, config files, or hybrid. Decision and rationale._

## Setup workflow

_Step-by-step user journey from unboxing to first experiment, including
module layout._

## Calibration workflow

_How users calibrate. Cross-reference [`calibration.md`](calibration.md)._

## Common task templates

_List of pre-built templates (e.g. bandit, reaction time, unrestricted free
feed) the platform ships with._

## FED3-style precedent

_Notes from FED3 review: what we adopt, what we change, what we explicitly
avoid._

## User flexibility boundaries

- Where users **need** flexibility.
- Where users **should not** have flexibility.
- Override needs for advanced users.

## Minimum viable UI mockup

_Link to mockup file or screenshot. Should be enough for ABC to give
go/no-go feedback in Phase 3A._

## User stories

_Numbered, named, prioritized. Each maps to a primary persona (e.g. ABC
technician, HLAB experimenter)._

## Open questions

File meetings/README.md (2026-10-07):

# Meeting Notes

Lightweight record of cross-lab meetings and major site events. The intent is
to capture decisions and action items so the rest of the team can stay aligned
without attending every call. Full transcripts are not required.

Weekly shipped / blocked / next updates live in [`pulse/`](../pulse/), not
here.

## How to add a note

1. Copy [`TEMPLATE.md`](TEMPLATE.md) to a new file named
   `YYYYMMDD_meeting.md`.
   Example: `20260721_meeting.md`.
2. Fill in attendees, agenda, decisions, and action items.
3. Two notes on the same day get a short suffix, for example
   `20261005_abc_meeting.md` and `20261005_hlab_meeting.md`.
4. Add the note to the index below.

## Index

| Date | Topic | Attendees | Notes |
| --- | --- | --- | ----- |
| 2026-07-21 | Initial discussion with ABC and Hengen Lab — implementation plan, pellet presence, experiment tasks | NTH (Matt, Jemin), ABC, HLAB (Ravi Chopra) | [`20260721_meeting.md`](20260721_meeting.md) |
| 2026-08-14 | First SFM delivery to Hengen Lab — two-module two-armed bandit; analysis SDK | NTH, HLAB (Ravi Chopra) | [`20260814_meeting.md`](20260814_meeting.md) |
| 2026-08-31 | ABC site tour — behavior-box fit, cleaning, replicate HLAB assembly | NTH, ABC | [`20260831_meeting.md`](20260831_meeting.md) |
| 2026-09-30 | ABC monthly — behavior-box setup and Katie training | NTH (Matt, Jemin), ABC (Katie) | [`20260930_meeting.md`](20260930_meeting.md) |
| 2026-10-05 | ABC weekly — first experiment startup with Katie | NTH (Jemin), ABC (Katie) | [`20261005_abc_meeting.md`](20261005_abc_meeting.md) |
| 2026-10-05 | HLAB — two-arm learning, `PelletLost` on raise, incomplete lift | NTH (Jemin), HLAB (Ravi Chopra) | [`20261005_hlab_meeting.md`](20261005_hlab_meeting.md) |

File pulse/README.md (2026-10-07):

# Weekly pulse

Short, dated progress notes — what shipped, what is in flight, and what is
blocked. One entry per **project week**. Week 0 starts 2026-06-08 (Monday).
Weeks run Monday–Sunday.

Meeting decisions belong in [`meetings/`](../meetings/). This log is the
status heartbeat so anyone can see progress without reading every commit.

## How to update

1. Each Monday, copy [`TEMPLATE.md`](TEMPLATE.md) to the **top** of
   [`log.md`](log.md) (newest week first).
2. Fill shipped / in progress / blocked / next. Bullets, not prose.
3. If a cross-lab meeting or site event happened, link the meeting note.
4. When the week number or phase changes, update the **Current status**
   tables in [`PROJECT.md`](../PROJECT.md) and [`README.md`](../README.md).

## Week index

| Week | Dates (Mon–Sun) | Phase | Pulse |
| ---- | --- | --- | ----- |
| 0 | 2026-06-08 – 06-14  | 0 Architecture | [log](log.md#week-0--2026-06-08-to-2026-06-14) |
| 1 | 2026-06-15 – 06-21  | 0 Architecture | [log](log.md#week-1--2026-06-15-to-2026-06-21) |
| 2 | 2026-06-22 – 06-28  | 1A / 1B Kickoff | [log](log.md#week-2--2026-06-22-to-2026-06-28) |
| 3 | 2026-06-29 – 07-05  | 1A / 1B Kickoff | [log](log.md#week-3--2026-06-29-to-2026-07-05) |
| 4 | 2026-07-06 – 07-12  | 1A / 1B Kickoff | [log](log.md#week-4--2026-07-06-to-2026-07-12) |
| 5 | 2026-07-13 – 07-19  | 2 Engineering sprint | [log](log.md#week-5--2026-07-13-to-2026-07-19) |
| 6 | 2026-07-20 – 07-26  | 2 Engineering sprint | [log](log.md#week-6--2026-07-20-to-2026-07-26) |
| 7 | 2026-07-27 – 08-02  | 2 Engineering sprint | [log](log.md#week-7--2026-07-27-to-2026-08-02) |
| 8 | 2026-08-03 – 08-09  | Alpha deployment | [log](log.md#week-8--2026-08-03-to-2026-08-09) |
| 9 | 2026-08-10 – 08-16  | Alpha deployment (HLAB pair)  | [log](log.md#week-9--2026-08-10-to-2026-08-16) |
| 10 | 2026-08-17 – 08-23  | Alpha deployment (`sfm-analysis`) | [log](log.md#week-10--2026-08-17-to-2026-08-23) |
| 11 | 2026-08-24 – 08-30  | Alpha deployment | [log](log.md#week-11--2026-08-24-to-2026-08-30) |
| 12 | 2026-08-31 – 09-06  | ABC tour / two-node box path  | [log](log.md#week-12--2026-08-31-to-2026-09-06) |
| 13 | 2026-09-07 – 09-13  | ABC two-node box in build | [log](log.md#week-13--2026-09-07-to-2026-09-13) |
| 14 | 2026-09-14 – 09-20  | Rebaseline; 3A next | [log](log.md#week-14--2026-09-14-to-2026-09-20) |
| 15 | 2026-09-21 – 09-27  | 3A Feedback + maintainability | [log](log.md#week-15--2026-09-21-to-2026-09-27) |
| 16 | 2026-09-28 – 10-04  | 3A ABC box + training | [log](log.md#week-16--2026-09-28-to-2026-10-04) |
| 17 | 2026-10-05 – 10-11  | 3A first runs (current) | [log](log.md#week-17--2026-10-05-to-2026-10-11) |

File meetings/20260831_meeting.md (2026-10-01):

# Meeting: ABC site tour — behavior-box fit and cleaning

- **Date:** 2026-08-31
- **Time / duration:**
- **Attendees:** NTH, ABC
- **Phase:** Alpha deployment / ABC install path (not Phase 5)

## Agenda

1. Tour of Animal Behavior Core facilities
2. Whether a retrofitted box can serve as the ABC behavior box
3. Cleaning protocol and what ABC needs for day-to-day flexibility

## Discussion

- Site tour at ABC to judge how SFM hardware sits in their space.
- Discussed **retrofitting an existing box** as the behavior box, and whether
  that fit is good enough for ABC’s cages, racks, and technician workflow.
- Cleaning protocol came up as a first-class constraint: ABC needs a path
  that survives routine clean and does not lock them into a one-off NTH
  assembly.
- For flexibility, ABC can **replicate the behavior-box assembly already
  running at Hengen Lab** rather than inventing a separate retrofit. That
  keeps the two labs on the same mechanical recipe (two-node setup) while
  ABC’s first pair is built.

## Decisions

- Prefer replicating the Hengen Lab behavior-box assembly for ABC over a
  one-off retrofit, so cleaning and maintenance stay the same across labs.
- ABC’s first deployment is a **two-node behavior box** (same class as the
  Aug 14 HLAB pair), not the n=9 field-test array.

## Action items

| Owner | Action | Due |
| ----- | --- | --- |
| NTH | Build ABC’s first two-node behavior box from the HLAB recipe | Done 2026-09-30 ([setup](20260930_meeting.md)) |
| ABC | Confirm operational protocols / technician constraints against that assembly | After delivery |

## Open questions / parking lot

- Exact install location and rack constraints once the two-node box is on
  site.
- Any ABC-specific cleaning chemicals or interval that the HLAB assembly
  does not already tolerate.

## References

- Related ADRs:
- Related docs: [`docs/maintenance.md`](../docs/maintenance.md),
  [`docs/validation-plan.md`](../docs/validation-plan.md)
- Related PROJECT.md phase / goals:
  [Phase 3A — ABC + HLAB Feedback + Maintainability](../PROJECT.md#phase-3a--abc--hlab-feedback--maintainability)

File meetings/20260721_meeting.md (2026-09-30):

# Meeting: Initial discussion with ABC and Hengen Lab — implementation plan

- **Date:** 2026-07-21
- **Time / duration:**
- **Attendees:** Matt Gaidica (NTH), Jemin (NTH), ABC team, Ravi Chopra (HLAB)
- **Phase:** Phase 2 — NTH Engineering Sprint

## Agenda

1. Implementation plan with ABC and Hengen Lab
2. Node-module upgrades: pellet presence sensing
3. Experiment tasks and alpha software path
4. Home-cage requirements and IACUC implications

## Discussion

- First joint implementation discussion with ABC and Hengen Lab.
- Matt introduced the hardware; Jemin introduced the alpha software.
- Agreed the node module needs an upgrade to **pellet presence sensing**, not
  dispense-only, so experiment tasks can reason about whether a pellet is
  actually in the well.
- Covered experiment-task needs for both labs (common ABC tasks and HLAB
  custom experiments) and a week-8 rollout target as then planned.
- **Project status at the meeting:** awaiting beam-break sensor PCBs (then
  expected July 28) and finalizing 3D design. Alpha software had exposed
  events and demonstrated connectivity. NTH was preparing a build week and
  beta hardware/software distribution.

## Decisions

- Upgrade the node module for pellet presence sensing (priority over later
  detector work).
- Treat experiment-task support as part of the same implementation plan, not
  a follow-on after hardware freeze.
- Add bedding offset so “home cage” intent is met.
- Pursue IACUC protocol amendment.

## Action items

| Owner | Action | Due |
| --- | --- | --- |
| NTH | Pellet-presence sensing on the node module | TBD |
| NTH | Experiment-task support on alpha software | TBD |
| Matt (NTH) | Provide brief for IACUC amendment | TBD |

## Open questions / parking lot

-

## References

- Related ADRs:
- Related docs: [`docs/dispense-cycle.md`](../docs/dispense-cycle.md)
  (pellet presence), [`docs/user-api.md`](../docs/user-api.md) (experiment
  tasks)
- Related PROJECT.md phase / goals:
  [Phase 2 — NTH Engineering Sprint](../PROJECT.md#phase-2--nth-engineering-sprint)

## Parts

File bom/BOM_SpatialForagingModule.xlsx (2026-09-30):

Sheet: Electronics
Modules | 16
Item | Pcs/Module | Item Cost | Total Pcs | Req. Items | Total Cost | Link | Notes
Rpi kit | 1 | $219.00 | 1 | 0 | $219.00 | https://a.co/d/0coOI5yY
Monitor | 1 | $69.00 | 1 | 0 | $69.00 | https://a.co/d/09dVZbY1
HDMI cable | 1 | $13.00 | 1 | 0 | $13.00 | https://a.co/d/0hCpHv8v
Keyboard & Mouse | 1 | $37.00 | 1 | 0 | $37.00 | https://a.co/d/0ewPxBey
Headers 8.5mm | 1 | $7.00 | 1 | 0 | $7.00 | https://a.co/d/0ez4Hsjl
20mm standoff | 4 | $9.00 | 4 | 0 | $9.00 | https://a.co/d/0bluxMO1
M2.5 screws | 4 | $6.00 | 4 | 0 | $6.00 | https://a.co/d/0eXXSgv0
Power Supply | 1 | $25.00 | 1 | 0 | $25.00 | https://a.co/d/0hV6RBvV
Ethernet cable | 2 | $5.00 | 32 | 0 | $80.00 | https://a.co/d/09iXwi5c
DC Power cable | 2 | $10.00 | 32 | 0 | $96.00 | https://a.co/d/0ivINniR
28BYJ-48 Motors | 2 | $6.00 | 32 | 0 | $192.00 | https://a.co/d/0dLrfPuQ
QT cables 200mm | 3 | $6.00 | 48 | 0 | $288.00 | https://www.digikey.com/en/products/detail/adafruit-industries-llc/4401/10824265

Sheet: Hardware
Modules |  | 16
Item | Part Number | Item Pcs | Pcs/Module | Total Pcs | Req Items | Item Cost | Total Cost | (Cost/Pc) | Link | Notes
M3 × 16 button head | 94500A265 | 100 | 4 | 64 | 1 | $9.87 | $9.87 | $0.15 | https://www.mcmaster.com/94500A265/ | User acrylic mount
M2 × 5 countersunk | 92125A051 | 50 | 8 | 128 | 3 | $8.64 | $25.92 | $0.20 | https://www.mcmaster.com/92125A051/ | Clamshell
1.5 × 4.7625 mm tapping | 99512A108 | 50 | 12 | 192 | 4 | $12.53 | $50.12 | $0.26 | https://www.mcmaster.com/99512A108/ | Beam break mounts, etc.
M4 × 3 button head screw |  | 50 | 4 | 64 | 2 | $5.72 | $11.44 | $0.18 | https://a.co/d/08jMKRfI | Motor mounts
M3 × 6 countersunk | 92125A126 | 100 | 6 | 96 | 1 | $7.46 | $7.46 | $0.08 | https://www.mcmaster.com/92125A126/ | Brackets
M2 × 10 countersunk | 92125A056 | 25 | 2 | 32 | 2 | $5.20 | $10.40 | $0.33 | https://www.mcmaster.com/92125A056/ | Spring mount
M3 × 10 countersunk | 92125A130 | 100 | 16 | 256 | 3 | $8.77 | $26.31 | $0.10 | https://www.mcmaster.com/92125A130/ | Brackets, top plate
M2.5 × 4 set screw | 92015A095 | 50 | 2 | 32 | 1 | $10.44 | $10.44 | $0.33 | https://www.mcmaster.com/92015A095/ | Motors
M2 × 20 countersunk | 92125A611 | 10 | 2 | 32 | 4 | $7.00 | $28.00 | $0.88 | https://www.mcmaster.com/92125A611/ | Electronics
Mini Spring | 9433K256 | 1 | 1 | 16 | 16 | $4.70 | $75.20 | $4.70 | https://www.mcmaster.com/9433K256/ | Clamshell
M2 x 5mm Standoff |  | 50 | 4 | 64 | 2 | $9.40 | $18.80 | $0.29 | https://a.co/d/0c5kMODr | Electronics
 |  |  |  |  |  | total | $273.96
 |  |  |  |  |  | total/module | $17.12

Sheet: Behavior Box
Item | Part Number | Item Pcs | Req. pcs | Item Cost | Total Cost | Link | Notes
3 ft. T-Slot | 47065t101 | 2 | 2 | $20.00 | $40.00 | https://www.mcmaster.com/products/47065t101/ | In future willl replace with alternative option with tapped center and 1 1/2 ft length
1/4"-20 flat head | 92210A537 | 1 | 1 | $11.50 | $11.50 | https://www.mcmaster.com/92210A537/
Clear Acrylic |  | 4 | 2 | $24.00 | $96.00 | https://www.tapplastics.com/product/plastics/cut_to_size_plastic/acrylic_sheets_clear/508 | 6mm 420x420
White Acrylic |  | 2 | 1 | $41.00 | $82.00 | https://www.tapplastics.com/product/plastics/cut_to_size_plastic/acrylic_sheets_color/341 | 6mm 630x400
 |  |  |  | Total | $229.50

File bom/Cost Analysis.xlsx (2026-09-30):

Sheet: Cost Analysis
Type | Cost | Note |  |  |  |  | Orders | Cost | Note
PCBA VFM | $360.00 | First batch of 5 for VFM | Total | $8720.00 | Spent | $3121.00 | PCBA 6-19 | $520.00 | VFM 6 and Base station 5
PCBA VFM | $1200.00 | Qty. 30 of VFM | Budget | $11000.00 | Budget | $11000.00 | Hub General 6-12 | $404.00
PCB for CAN HAT | $80.00 |  | Remaining | $2280.00 | Remaining | $7879.00 | Amazon 6-12 | $400.00 | Pi kit, wires, motors and headers
Other PCBs | $600.00 | Photogates, any sub module |  |  |  |  | Digikey 6-19 | $50.00 | isolator
PCB Components | $600.00 | Parts for CAN HAT (worth to PCBA) |  |  |  |  | Amazon 6-22 | $16.00 | PEI plate for bambu
Wiring | $400.00 | Ethernet and Power cables |  |  |  |  | Amazon 7-13 | $18.00 | standoffs and headers
Raspberry pi | $1280.00 | 4 pi boards |  |  |  |  | Digikey 7-13 | $20.00 | 3.3v regulator
Pi Power and cooler | $120.00 |  |  |  |  |  | PCBA 7-15 | $337.00 | Photo gate breakout 90 pcs
3D Filament | $360.00 |  |  |  |  |  | PCB 7-16 | $100.00 | Touch sensing PCB
Acrylic | $1000.00 | we might support the entire build as part of the modules |  |  |  |  | Digikey 7-17 | $40.00 | QT cables 20 pcs
Motors | $300.00 |  |  |  |  |  | Amazon 7-21 | $245.00 | Rpi Canakit + standoffs and headers
Screws | $100.00 |  |  |  |  |  | McMaster 7-27 | $230.00 | Hardware for VFM
SendCutSend | $300.00 | Metal Cap Touch pads |  |  |  |  | Amazon 8-17 | $10.00 | Ethernet wire mount for ABC
Aluminum Extrusion + Brackets | $1000.00 | To support behavior boxes |  |  |  |  | Amazon | $100.00 | Vacuums
Anti-chew resin/metal parts | $600.00 |  |  |  |  |  | Bioserv 8-21 | $260.00 | Sugar pellets
Hub General | $420.00 | Cost link to the Hub General sheet |  |  |  |  | 80/20 Inc. 9-4 | $51.00 | Aluminium Extruder
 |  |  |  |  |  |  | Acrylic | $100.00 | Consumable
 |  |  |  |  |  |  | Hardware for ABC box | $220.00 | Acrylic, Extrusion, Screws and Taper set

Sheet: Hub General
Item | Price | Usage | Marketplace | Note
Docking station | $26.00 | For desk | https://a.co/d/07s29nJl |  | Total Cost | $420.00
Power supply | $19.00 | For desk | https://a.co/d/0cHJypZE
JBC C115105 | $100.00 | Tip for tweezer | https://www.tequipment.net/JBC/C115105/Tips/?v=0 | Qty. 2
JBC C115 113 | $100.00 | Fine tip for backup | https://www.tequipment.net/JBC/C115-TIP-KIT/Tips/?v=0
Caliper | $90.00 | Digital caliper | https://a.co/d/0f11Bh60
3mm drill bit | $6.00 | Drill bit | https://a.co/d/0bJEs9ge
Precision drill bit | $17.00 | Drill bit | https://a.co/d/00RdSovD
White PLA | $46.00 | Stocking | https://a.co/d/0h9pkCtd
PEI plate | $16.00 | X1C printer | https://a.co/d/0dKIXQPl

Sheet: VerticalForaging
Item | Price | Usage | Marketplace | Note
Ethernet cable | $28.90 | wiring | https://a.co/d/00HqSPSU | 3ft, 24pack | <- all white!
Base to cage | $15.95 |  | https://a.co/d/003clznl | 10ft, 5pack | <- all white!
DC power cable | $90.00 | wiring | https://a.co/d/0gsEHh0D | 3ft, 6pcs | <- all white!
28BYJ-48 Motors | $14.89 | drive | https://a.co/d/07NI8Ce2 | 6pcs
Main PSU for modules | $23.74 |  | https://a.co/d/02GKY84I | 12V, 8A, barrel plug | <- all white!
light pipe | $10.00 | LED | https://www.digikey.com/en/products/detail/bivar-inc/PLP1-625-F/586485

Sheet: piHat
Item | Qty. | Price | Total Cost | Usage | Marketplace | Note
Raspberry pi 5 16GB | 4 | $300.00 | $1200.00 | Base station | https://www.microcenter.com/product/702590/raspberry-pi-5
Power supply for pi | 4 | $11.00 | $44.00 | Power | https://a.co/d/03vkXWGH
Header Extender | 4 | $12.00 | $12.00 |  | https://a.co/d/05PbDtE7 | I would wait for this order if go with the Canakit to measure the height of that cooler.
Cooler | 4 | $12.00 | $48.00 |  | https://a.co/d/08atDlD6
Pi Kit | 4 | $219.00 | $876.00 |  | https://a.co/d/05suoWQt | comes w/ cooler and PSU
Keyboard | 4 | $37.00 | $148.00 |  | https://a.co/d/06HkCOwA

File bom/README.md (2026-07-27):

# Budget and BOM Tracking

This folder tracks the project budget against the McDonnell NRP award and
holds the primary Bill of Materials (BOM).

This file is for planning visibility, not engineering: it should answer "are
we on budget?" at a glance.

## Award

**Total: $40,000** over 12 months. Source:
[`../references/McDonnell-NRP_GAIDICA.pdf`](../references/McDonnell-NRP_GAIDICA.pdf).

## Budget allocation

| Recipient | Category | Awarded | Committed | Spent | Remaining |
| --- | --- | --- | --- | ----- | --- |
| NTH | Engineering salary (electronics, firmware, UI, integration) | $15,000 | $0 | $0 | $15,000 |
| NTH | Fabrication & prototyping equipment | $5,000 | $0 | $0 | $5,000 |
| ABC | Benchmarking module array (n=9) | $3,000 | $0 | $0 | $3,000 |
| ABC | Behavioral testing, animals, technician effort | $7,000 | $0 | $0 | $7,000 |
| HLAB | Validation module array (n=9) | $3,000 | $0 | $0 | $3,000 |
| HLAB | Electrophysiology validation, animals, recording support | $7,000 | $0 | $0 | $7,000 |
| **Total** | | **$40,000** | **$0**  | **$0** | **$40,000** |

> Lab abbreviations are defined in the [main README — Abbreviations](../README.md#abbreviations).

## Canonical BOMs

| BOM | Location | Notes |
| --- | --- | --- |
| Primary BOM | [`BOM_SpatialForagingModule.xlsx`](BOM_SpatialForagingModule.xlsx) | Module bill of materials |

## Unit economics

Per-module and per-base-station unit economics are summarized here once the
production-intent BOMs are finalized in Phase 4, confirming that the
n=9 + n=9 build fits the budget.

| Item | Estimated cost | Quantity | Subtotal |
| --- | --- | --- | --- |
| Module (production) | TBD | TBD | TBD |
| Base station | TBD | TBD | TBD |
| Support tools | TBD | TBD | TBD |

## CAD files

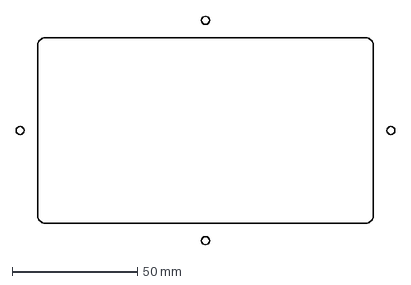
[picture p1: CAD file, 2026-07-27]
hardware/3D/UserDXF.dxf
151.2 x 91.3 mm

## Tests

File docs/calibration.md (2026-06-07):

# Calibration

Defines what must be calibrated, how often, and the user-facing procedures.

## Calibration targets

_Per-module: pellet delivery (mass/count), interaction sensor thresholds,
LED brightness, sync output timing — list every parameter that drifts._

## Calibration procedures

_Per-target step-by-step procedure. Should be executable by a non-engineer._

## Frequency

_Per-target recommended cadence. Tied to assumptions in
[`maintenance.md`](maintenance.md)._

## Required tools

_Calibration jigs, scales, sync probes. Should appear in the support-tool
BOM._

## Pass/fail criteria

_Quantitative thresholds. Where data is logged for traceability._

## Calibration record

_What gets stored per module (date, technician, value, drift)._

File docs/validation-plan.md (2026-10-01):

# Validation Plan

Defines what "validated" means for the Spatial Foraging Platform and how we
demonstrate it.

## Validation goals

Three pillars, mirroring the grant proposal:

1. **Engineering** — hardware reliability, communication integrity,
   reproducible build.
2. **Behavior** — animals engage robustly and self-initiate; reward delivery
   is reliable; common task structures run end-to-end.
3. **Recording** — compatibility with chronic electrophysiology and video;
   recovery of canonical signals (e.g. hippocampal spatial tuning,
   striatal/ACC decision-variable encoding).

## MVP validation (Phase 3B)

_One custom experiment running end-to-end with at least one animal._

## Field-test validation (Phase 5)

Phase 5 is planned for weeks 25–28 (2026-11-30 to 2026-12-27), after the
9-node PCBA and enclosure platform in Phase 4. It is **not** the current
window: ABC’s first two-node behavior box was set up 2026-09-30; n=9 field tests
follow once those boards and the enclosure are in hand.

### Reliability metrics

_Pellet delivery success rate, interaction sensing accuracy, mechanical
failures per module-day, communication errors per hour._

### Behavior metrics

_Engagement, session structure, task acquisition, exploration pattern._

### Recording metrics

_Sync precision, recording stability, recovery of canonical signals._

## Reference datasets

_Datasets that will be released alongside the manuscript. Format, hosting,
DOI plan._

## Analysis examples

Session analysis and printable HTML reports live in
[`packages/sfm-analysis`](https://github.com/Neurotech-Hub/SFM/tree/main/packages/sfm-analysis)
(`pip install sfm-analysis`, CLI `sfm-report`). Domain vocabulary, log columns,
and derived metrics:
[ANALYSIS_GUIDE.md](https://github.com/Neurotech-Hub/SFM/blob/main/packages/sfm-analysis/docs/ANALYSIS_GUIDE.md).
Operator commands: [README — Operations](../README.md#operations).

## Statistical and reporting plan

Session CSVs are the source of truth. HTML behavior reports
([`sfm-report`](https://github.com/Neurotech-Hub/SFM/tree/main/packages/sfm-analysis);
Pi wrapper [`run_report.py`](https://github.com/Neurotech-Hub/SFM/blob/main/packages/dev_gui/run_report.py))
are the operator-facing summary for ABC/HLAB: pellet accounting, retrieval
latency, presence, interaction funnel, faults, plus task-specific metrics
(bandit choice / WSLS / reversal). Combined reports support cohort tables and
learning curves. Pre-registered n, effect sizes, and success thresholds for
the manuscript are still open.

## Open questions

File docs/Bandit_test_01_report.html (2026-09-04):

# Bandit_test_01

Sessions: Bandit_test_01 · Design: Two-Armed Bandit — Behavior Report

Runs

1

Duration

21m 32s

Pellets presented → taken

18 → 18

take rate 100%

Time to first trial

20s

Fault intervals

1

## Session Timeline

### Bandit_test_01 · run 2

Bands:presencedome opendispense cyclefault

Markers:trial startscript stalledsession endLoaded (pellet)Pellet TakenNo-Feed PresentedFeed Skipped

Full-session overview (21m 32s).

Detail: 0s–10m 00s

Detail: 10m 00s–20m 00s

Detail: 20m 00s–21m 32s

## Session Provenance

### Bandit_test_01 · run 2

Experiment | two_armed_bandit
Nodes | [1, 2]
Seed | 2011668843
Identity | no subject parsed from session name
Duration | 21m 32s
End reason | stopped normally
Source file | /media/base-station-00/STORAGE/sfm_logs/Bandit_test_01.csv

### Configured parameters

arm_a | 1
arm_b | 2
block_size | 10
mimic | 1
next_trial_wait | presence_clear
nodes | [1, 2]
p_high | 0.8999999761581421
seed | 2011668843

## Data Quality

Bandit_test_01 · run 2: node 1: heartbeat counter shows -1 more pellet(s) presented than CAN events recorded (possible bus loss).

Bandit_test_01 · run 2: 30 row(s) logged after session_end (excluded from rate denominators).

## Retrieval Latency

### Bandit_test_01 · run 2

Time from pellet ready to Pellet Taken, per node (n=17).

node 1node 2

## Presence & Occupancy

### Bandit_test_01 · run 2

Node | Bouts | Median duration | Total occupancy | Occupancy %
1 | 21 | 6s | 2m 13s | 10%
2 | 28 | 1s | 1m 22s | 6%

## Interaction Funnel

### Bandit_test_01 · run 2

presentedapproacheddome openedtaken

Node | Presented | Approached | Dome opened | Taken | Approach w/o dome | Dome w/o take
1 | 17 | 14 | 14 | 10 | 0 | 4
2 | 18 | 12 | 10 | 7 | 2 | 3

## Throughput

### Bandit_test_01 · run 2

presentedtaken

## Faults & Downtime

### Bandit_test_01 · run 2

Node | Fault | Started at | Duration | Resolution
1 | PelletLost | 3m 09s | 11s | recovered

## Apparatus Health

### Bandit_test_01 · run 2

Event | Count | First at | Last at
bandit_trial_aborted | 1 | 3m 09s | 3m 09s
paused_for_fault | 1 | 3m 09s | 3m 09s
resumed_after_fault | 1 | 3m 20s | 3m 20s
script_timeout | 1 | 20s | 20s

## Choice Summary (beta)

### Bandit_test_01 · run 2

Trials

19

Valid

17

Analyzed (choice observed)

17

Side bias (P chose arm)

65%

Choice source for every metric below: first_visit (first_visit = first approach after both arms presented; also compared against first_dome and taken as a validity check).

Comparison | Agreement
first dome vs taken | 71%
first visit vs first dome | 88%
first visit vs taken | 82%

## Block-wise Choice (beta)

### Bandit_test_01 · run 2

Wilson 95% CI per block (n=17 analyzed trials).

## Reversal Learning (beta)

### Bandit_test_01 · run 2

Median trials-to-criterion (3 consecutive new-rich choices): 5

## Win-Stay / Lose-Shift (beta)

### Bandit_test_01 · run 2

win-stay 10/12, lose-shift 2/3 (95% Wilson CI shown).

## Latency by Arm Role (beta)

### Bandit_test_01 · run 2

Time from pellet ready to dome open, split by whether the cycle was baited (fed) or not (empty) — the empty-arm number is the cost of exploration (n=17 fed, 6 empty).

fed armempty arm

Generated 2026-08-20 23:39 UTC by run_report.py — VFM behavior report tool. Print with Ctrl+P / Cmd+P.

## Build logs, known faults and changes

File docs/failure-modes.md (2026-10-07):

# Failure Modes

What can go wrong on a foraging module, in plain language.

Two kinds of problem show up:

- **The module stops.** Both motors turn off, the status light on top stays
solid on, and the screen shows a fault. It will not deliver another pellet
until someone presses **Recover**. Recover only clears the error. It does
not move the plate back to a home position.
- **The module keeps going.** It tells you something looks off (a dome left
open, a calibration that did not take, a module that never checked in).
Nothing is stuck, and Recover is not required.

The name in parentheses is the label in the software, so you can match what
you read here to what the screen says.

## Errors that stop the module

### Out of pellets (`FeedTimeout`)

The wheel turned for **30 seconds** and no pellet settled on the plate.

A pellet has to sit in the sensor for about **2 seconds** before it counts.
A crumb that flashes through the beam is ignored, and the wheel keeps trying
inside that same 30 seconds.

**Usual cause.** The hopper is empty, a pellet is stuck in the wheel, or the
pellet sensor is unplugged.

**What to do.** Refill or clear the wheel, check that the pellet sensor sees
a pellet, then press Recover.

### Plate jammed on the way up (`Jam`)

The plate started to rise and, **5 seconds** later, it was still sitting on
the lower position sensor. It never got clear of that sensor.

This is not an empty hopper. An empty hopper is “Out of pellets.”

**Usual cause.** Something is blocking the plate, the lift motor is not
moving, or the lower sensor is stuck “on.”

**What to do.** Clear the path, make sure the plate can move up, then press
Recover.

### Pellet fell off on the way up (`PelletLost`)

A pellet was on the plate, the plate started to rise, and the pellet sensor
went empty for **half a second**. The module refuses to offer an empty plate
as if it still had a reward.

This check runs only when a pellet was actually loaded. An empty-plate trial
(no pellet on purpose) does not raise this error.

**Usual cause.** The pellet rolled off, the animal touched it during travel,
or the sensor cable is loose.

**Seen at Hengen Lab (2026-10-05).** A mouse waiting at an open dome can
grab the pellet while the plate is still rising. The sensor goes empty and
the module reports this fault. That is a taken pellet, not one that fell
off. See [the HLAB note](../meetings/20261005_hlab_meeting.md).

**Not built yet.** If the dome is already open, leave the pellet at the
loading position. If the dome opens during the rise, lower the plate
immediately so the animal cannot take the pellet early.

**What to do.** Look at the plate. Do not count this cycle as a pellet that
was offered. Press Recover, then dispense again.

### Plate did not finish its move (`ActuatorTimeout`)

The lift motor was given about **8 seconds** for one part of the move and
did not finish. The screen uses one name for all of these. The line just
before the fault tells you which part it was:

| What it was doing | What went wrong |
| --- | --- |
| Moving up off the lower sensor | It did not get clear in time. |
| Moving down to pick up a pellet | It never found the lower sensor. It tries once more only if it already knows the plate is below that sensor. A second miss stops the module, so it does not drive upward into the hard stop. |
| Dropping a little past that sensor | It found the sensor, then did not finish the short extra drop where the pellet lands. |
| Lifting the plate to the animal | It did not reach the top in time. If it never even leaves the lower sensor, you will usually see **Plate jammed** first. |

**Usual cause.** The lift motor is stalled, unplugged, or blocked, or the
lower sensor never sees the plate.

**Seen at Hengen Lab (2026-10-05).** One node does not raise all the way to
the top. The cause is still open. See
[the HLAB note](../meetings/20261005_hlab_meeting.md).

**What to do.** Free the plate, check the lift motor and the lower sensor,
then press Recover.

### Waiting for the other module (not an error)

On a trial where this module is not supposed to give a pellet, it lowers,
then waits until the other module starts to rise, and rises with it. There
is no timer. If the other module never rises, this plate simply stays down
until someone presses Recover. The screen does not call this a fault.

## Messages that do not stop the module

### Dome left open (`DomeOpenWarning`)

The dome has been open for **30 seconds**. The module says so once, then
keeps working. Closing the dome and opening it again allows a new warning.

The top status light does not change. The small onboard light follows the
dome: lit means open.

**What to do.** Close the dome. If it will not close on its own, check the
spring and that nothing is holding it up.

### Module never appeared (`NotInitialized`)

The module could not start its network connection, so the base station never
hears from it. There is no fault message to clear, because the module is not
on the network. The status light stays in its fast boot blink.

**What to do.** Power-cycle the module. If it still never appears, the
network hardware on that board needs a look, or the firmware needs to be
loaded again.

### Odd fault code (`InvalidData`)

The software knows this name, but current modules never send it. If a log
shows it, that message did not come from this firmware.

### Presence calibration did not take

Calibrating the “is an animal here?” pad takes about **5 seconds** with an
empty cage. If it does not collect enough quiet readings, it fails and keeps
the old setting. The confirm blink does not play.

Starting a second calibration while one is already running does nothing. It
is not a failure.

**What to do.** Make sure the cage is empty and still, then calibrate again.

### A setting was rejected

If the base station sends a setting the module cannot use (for example a
blank or nonsense presence sensitivity), the module answers “not applied”
and keeps the old value. The module does not stop. A heartbeat that is set
too fast is slowed to a safe rate and still counts as applied.

### Module never got an ID

The status light blinks slowly (about once a second). The module is on, but
it is waiting for the base station to claim it. It will keep asking. It does
not call this a fault, and it will not pass power down the chain to the next
module until it is claimed.

**What to do.** Check that the first cable from the base station is seated,
and that the modules are chained in order. Holding the module button for
about **3 seconds** forgets its saved ID so it can be claimed again.

### A message was missed

If the network is briefly too busy, one update can be dropped. The module
does not stop. The next regular status update fills in the gap: whether it
is faulted, how many pellets it has offered, and how many were taken.

### Dispense did nothing

A dispense is ignored while the module is already moving, waiting, or
stopped on a fault. It does not announce the ignore. Press Recover if it is
faulted, then dispense again.

A pellet already sitting on the plate is not an error. The module skips
loading another one and offers the one that is already there.

## What you see

| What you see | What it means |
| --- | --- |
| Small light blinking quickly | The module is turning on. |
| Top light blinking slowly | It is on and waiting to be given an ID. |
| Top light off | It is ready. Not faulted. |
| Top light solid on | It has stopped on a fault. Press Recover after you fix the cause. |
| Top light blinks fast for a couple of seconds | Someone pinged this module, so you can see which box it is. |
| Screen: “Out of pellets…” | The wheel never delivered a pellet. |
| Screen: “Jam — load sensor still blocked…” | The plate did not get off the lower sensor. |
| Screen: “Pellet lost…” | The pellet left the plate while it was rising. |
| Screen: “Actuator fault…” | The lift did not finish its move. |

## Module looks offline

The module does not decide this itself. The base station marks it offline
when it has been silent for about **three times** its usual check-in.

In normal use that check-in is every minute, so a module looks offline after
about **3 minutes** of silence. Right after power-up, before the base station
has set that pace, the window is shorter (about 15 seconds).

**What to do.** Check the network cable, that the module has power, and that
the end of the chain is terminated. A module that never started its network
connection (see above) will stay silent until it is power-cycled or reloaded.
When it speaks again, the base station marks it online.

## Cross-references

- `[dispense-cycle.md](dispense-cycle.md)` — how a normal pellet delivery works.
- `[function-checks.md](function-checks.md)` — how to confirm a module is healthy.
- `[maintenance.md](maintenance.md)` — checks that prevent these failures.
- Technical constants and message layouts live in the [SFM](https://github.com/Neurotech-Hub/SFM) firmware docs (`firmware/docs/`).

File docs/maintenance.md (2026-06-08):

# Maintenance

Defines cleaning, access, service, and replacement assumptions for the
platform.

## Maintenance intervals

| Component / activity | Recommended interval | Notes |
| --- | --- | ----- |
| _example: pellet feeder cleaning_ | _weekly_ | _link to procedure_ |

## Cleaning workflow

_Step-by-step cleaning procedure. Disassembly steps, allowed solvents,
re-assembly checks._

## Physical access

_Notes on what needs to be reachable in-cage and how the form factor
supports that. Identify pain points found by ABC during Phase 3A review._

## Replaceable components

_List of items expected to wear or break, with replacement procedures and
sourcing notes (link to BOM)._

## User-facing service alerts

_What the system tells the user when maintenance is due. Cross-reference
[`failure-modes.md`](failure-modes.md)._

## Auto-detected vs manual checks

- Auto-detected: _list_
- Requires manual inspection: _list_

## Open questions

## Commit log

2026-07-27 Advance project status to Phase 2 Week 7 and capture July 22 meeting.
    Record alpha hardware/software status, primary module BOM, hardware artifacts, and ABC/HLAB intro decisions including the IACUC brief action.
    [BOM_SpatialForagingModule.xlsx, UserDXF.dxf]
2026-07-27 Document module mounting hardware and surface the Fusion design link.
    Add hardware README with DXF/fastener notes and promote the View Design link in the top-level README.
2026-07-27 Electronics BoM
    [BOM_SpatialForagingModule.xlsx]
2026-07-28 Motor screws
    [BOM_SpatialForagingModule.xlsx]
2026-08-06 Updated m2 screws
    [BOM_SpatialForagingModule.xlsx]
2026-08-06 part number correction
    [BOM_SpatialForagingModule.xlsx]
2026-08-18 reporting and sync functionality docs
    [BOM_SpatialForagingModule.xlsx]
2026-09-30 updates till week of 21st Sep
    [BOM_SpatialForagingModule.xlsx, Cost Analysis.xlsx]
